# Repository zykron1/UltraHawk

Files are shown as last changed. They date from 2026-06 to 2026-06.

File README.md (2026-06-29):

# UltraHawk
A custom fully autonomous drone designed to run custom firmware on a fully custom flight controller. It is capable of autonomously navigating to waypoints.

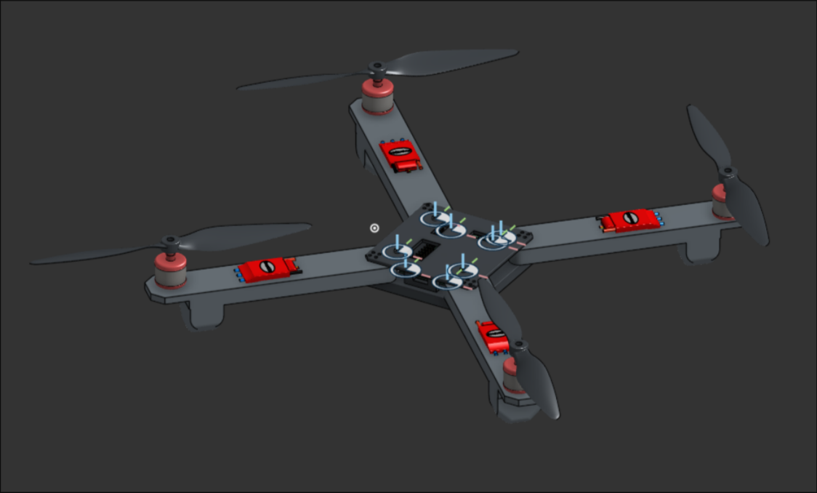
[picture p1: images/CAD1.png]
drone


Ultrahawk utilizes a fully custom PCB made out of SMT components that can be manufactured via a pick-and-place machine, or manually soldered on via hot plate.
You may find KiCAD files in the pcb directory, along with the production folder including a .zip file for easy export to PCB services as JLCPCB and PCBWay.
Components may be found in the `bom.csv` file containing the LCSC part numbers for each part.

UltraHawk also uses a custom frame that is designed to be 3D printed. CAD files for this can be found in the `CAD` folder as `.step` files.

The drone can then be assembled using the rest of the parts such as motors, esc's, and batteries, all of which can be found in the `bom.csv` file.
Perliminary firmware for the project may also be found in the `firmware` directory.

See bom.csv for full price breakdown.
See JOURNAL.md for full work log.

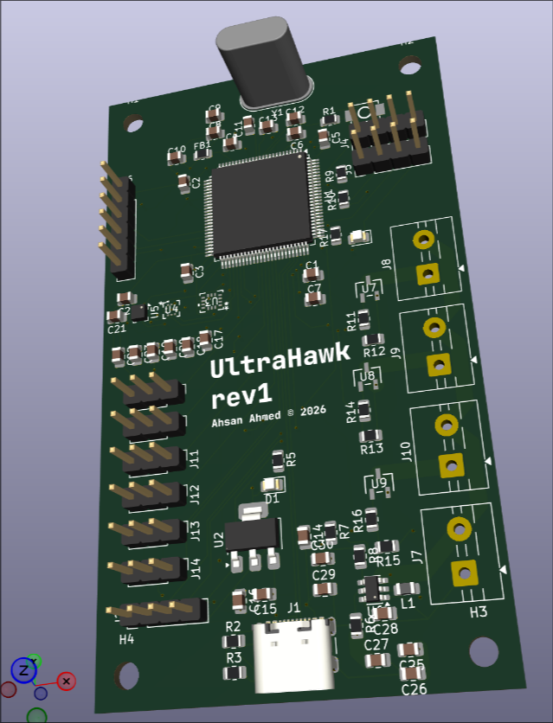
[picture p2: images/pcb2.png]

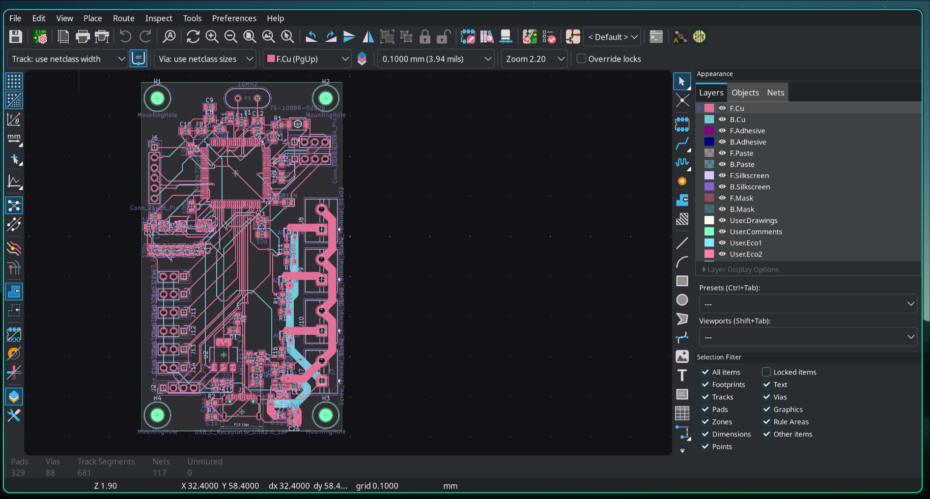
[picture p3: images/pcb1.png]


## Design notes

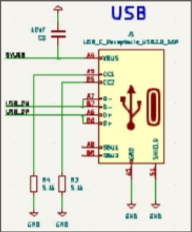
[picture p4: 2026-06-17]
images/usbc.png

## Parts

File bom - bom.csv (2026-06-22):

Designator | Footprint | Quantity | Value | LCSC Part # | Cost Per Unit | Cost | Note
C1, C11, C17, C18, C19, C2, C20, C21_2, C21, C23, C24, C3, C4, C5, C6, C27, C28 | 805 | 17 | 100n | C344180 | $0.02 | $0.35 | Multiples of 10
C10, C14, C9 | 805 | 3 | 1u | C24123 | $0.0195 | $0.39 | moq 20
C12, C13 | 805 | 2 | 34p | C3894194 | $0.0017 | $0.09 | moq 50
C15, C16 | 805 | 2 | 22u | C602037 | $0.1138 | $1.14 | moq 10
C22 | 805 | 1 | 1uf | C28323 | $0.0469 | $0.94 | moq 20
C25, C26 | 805 | 2 | 10µF | C1713 | $0.0491 | $0.98 | moq 20
C29, C30 | 805 | 2 | 22µF | C5674 | $0.07 | $0.70 | moq 10
C7 | 805 | 1 | 10u | C17024 | $0.04 | $0.84 | moq 20
C8 | 805 | 1 | 10n | C1710 | $0.01 | $0.47 | moq 50
D1 | 805 | 1 | RED | C84256 | $0.01 | $0.67 | moq 50
D2 | 805 | 1 | GREEN | C5879267 | $0.42 | $0.42 | no moq
FB1 | 603 | 1 | 120R | C14709 | $0.01 | $0.74 | moq 50
J1 | USB_C_Receptacle_GCT_USB4105-xx-A_16P_TopMnt_Horizontal | 1 | USB_C_Receptacle_USB2.0_16P | C5184243 | $1.17 | $1.17 | no moq
J10, J7, J8, J9 | TerminalBlock_MaiXu_MX126-5.0-02P_1x02_P5.00mm | 4 | Screw_Terminal_01x02 | C5188434 | $0.06 | $0.62 | moq 10
J11, J12, J13, J14, J15, J3 | PinHeader_1x03_P2.54mm_Vertical | 6 | Conn_01x03_Pin | C2337 | $0.16 | $0.78 | moq 5
J2, J4, J5 | PinHeader_1x04_P2.54mm_Vertical | 3 | Conn_01x04_Pin | sharing from above | sharing from above | 0 | sharing from above
J6 | PinHeader_1x06_P2.54mm_Vertical | 1 | Conn_01x06_Pin | sharing from above | sharing from above | 0 | sharing from above
L1 | 805 | 1 | 3.3uh | C18734461 | $0.02 | $0.12 | moq 5
R1, R12, R13, R15, R6, R7 | 805 | 6 | 10k | C84376 | $0.00 | $0.38 | moq 100 | Factory ded
R10, R9 | 805 | 2 | 4.7k | C4176634 | $0.01 | $0.01 | no moq | Factory ded
R11, R14, R16 | 805 | 3 | 100 | C2907218 | $0.00 | $0.32 | moq 100 | Factory ded
R17 | 805 | 1 | 220 | C104105 | $0.00 | $0.26
R2, R3 | 805 | 2 | 5.1k | C2930296 | $0.00 | $0.22 | moq 100
R5 | 805 | 1 | 1k5 | C416128 | $0.00 | $0.26 | moq 100
R8 | 805 | 1 | 54.9k | C137510 | $0.00 | $0.28 | moq 100 | Factory ded
SW1 | SW-SMD_L3.9-W3.0-P4.45 | 1 | TS-1088R-02026 | C455280 | $0.06 | $0.60 | moq 5
U1 | LQFP-100_14x14mm_P0.5mm | 1 | STM32H723VGTx | C730142 | $6.99 | $6.99 | no moq
U2 | SOT-223-3_TabPin2 | 1 | AMS1117-3.3 | C6186 | $0.20 | $0.99 | moq 5
U3 | BMI270_BOS | 1 | BMI270 | C2836813 | $4.15 | $4.15 | no moq
U4 | QFN10_BMP581_BOS | 1 | BMP581 | C5362283 | $4.31 | $4.31 | no moq
U5 | LGA-12_2x2mm_P0.5mm | 1 | LIS3MDL | C478483 | $5.04 | $5.04 | no moq
U6 | SOT-23-6 | 1 | TPS565208 | C2650336 | $0.44 | $0.44 | no moq
U7, U8, U9 | SOT-23-3L_AOS | 3 | AO3400A | C20917 | $0.08 | $0.42 | moq 5
Y1 | Crystal_HC49-U_Vertical | 1 | 16MHZ | C326538 | $0.53 | $0.53 | no moq
 |  |  |  |  |  | $35.63
Name | Cost | Link
JLCPCB Stencil+PCB+Shipping | $18.87 | n/a
BLDC + ESC + Props | $55.99 | https://www.amazon.com/gp/product/B0BW5H7Y8Q/
OVONIC 3S Lipo Battery 50C 5200mAh | $25.54 | https://www.amazon.com/5200mAh-Battery-Connector-Airplane-Helicopter/dp/B07L69B8V6/
LCSC Total(SEE LCSC.CSV!!!) | $35.63 | n/a
LCSC Shipping | $20 | estimate
 | $156.03

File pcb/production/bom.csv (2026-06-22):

Designator | Footprint | Quantity | Value | LCSC Part #
C1, C11, C17, C18, C19, C2, C20, C21_2, C21, C23, C24, C3, C4, C5, C6 | 0805 | 15 | 100n
C10, C14, C9 | 0805 | 3 | 1u
C12, C13 | 0805 | 2 | 34p
C15, C16 | 0805 | 2 | 22u
C22 | 0805 | 1 | 1uf
C25, C26 | 0805 | 2 | 10µF
C27, C28 | 0805 | 2 | 0.1µF
C29, C30 | 0805 | 2 | 22µF
C7 | 0805 | 1 | 10u
C8 | 0805 | 1 | 10n
D1 | 0805 | 1 | RED
D2 | 0805 | 1 | GREEN
FB1 | 0603 | 1 | 120R
J1 | USB_C_Receptacle_GCT_USB4105-xx-A_16P_TopMnt_Horizontal | 1 | USB_C_Receptacle_USB2.0_16P
J10, J7, J8, J9 | TerminalBlock_MaiXu_MX126-5.0-02P_1x02_P5.00mm | 4 | Screw_Terminal_01x02
J11, J12, J13, J14, J15, J3 | PinHeader_1x03_P2.54mm_Vertical | 6 | Conn_01x03_Pin
J2, J4, J5 | PinHeader_1x04_P2.54mm_Vertical | 3 | Conn_01x04_Pin
J6 | PinHeader_1x06_P2.54mm_Vertical | 1 | Conn_01x06_Pin
L1 | IND-SMD_L5.8-W5.2 | 1 | 3.3uh | C2826659
R1, R12, R13, R15, R6, R7 | 0805 | 6 | 10k
R10, R9 | 0805 | 2 | 4.7k
R11, R14, R16 | 0805 | 3 | 100
R17 | 0805 | 1 | 220
R2, R3 | 0805 | 2 | 5.1k
R5 | 0805 | 1 | 1k5
R8 | 0805 | 1 | 54.9k
SW1 | SW-SMD_L3.9-W3.0-P4.45 | 1 | TS-1088R-02026 | C455280
U1 | LQFP-100_14x14mm_P0.5mm | 1 | STM32H723VGTx
U2 | SOT-223-3_TabPin2 | 1 | AMS1117-3.3
U3 | BMI270_BOS | 1 | BMI270
U4 | QFN10_BMP581_BOS | 1 | BMP581
U5 | LGA-12_2x2mm_P0.5mm | 1 | LIS3MDL
U6 | SOT-23-6 | 1 | TPS565208
U7, U8, U9 | SOT-23-3L_AOS | 3 | AO3400A
Y1 | Crystal_HC49-U_Vertical | 1 | 16MHZ

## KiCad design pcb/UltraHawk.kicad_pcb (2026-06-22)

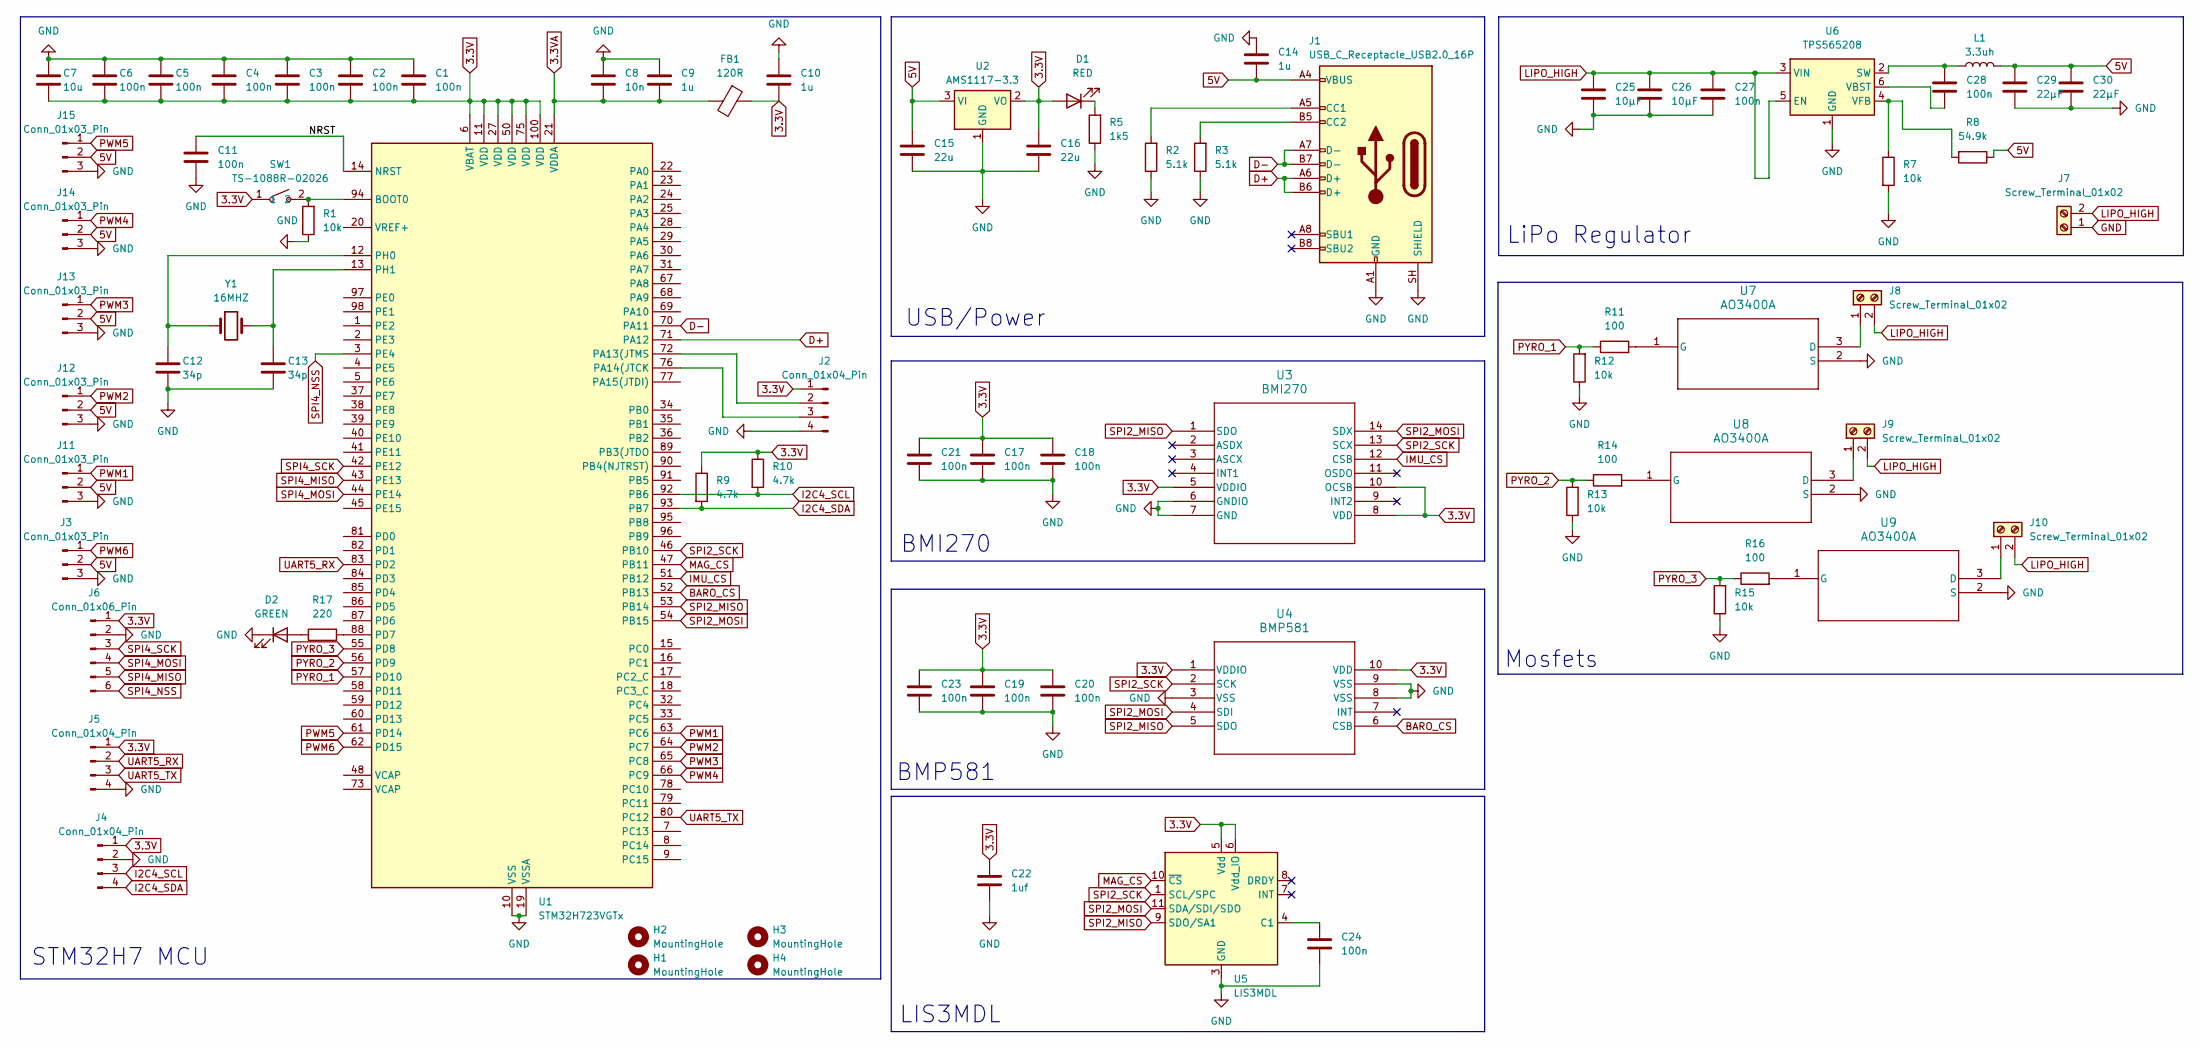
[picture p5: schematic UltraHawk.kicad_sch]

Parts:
C1, C2, C3, C4, C5, C6, C11, C17, C18, C19, C20, C21, C23, C24, C27, C28: 100n; C_0805_2012Metric
C7: 10u; C_0805_2012Metric
C8: 10n; C_0805_2012Metric
C9, C10, C14: 1u; C_0805_2012Metric
C12, C13: 34p; C_0805_2012Metric
C15, C16: 22u; C_0805_2012Metric
C22: 1uf; C_0805_2012Metric
C25, C26: 10µF; C_0805_2012Metric
C29, C30: 22µF; C_0805_2012Metric
D1: RED; LED_0805_2012Metric
D2: GREEN; LED_0805_2012Metric
FB1: 120R; R_0603_1608Metric_Pad0.98x0.95mm_HandSolder
H1, H2, H3, H4: MountingHole; MountingHole_3.2mm_M3
J1: USB_C_Receptacle_USB2.0_16P; USB_C_Receptacle_GCT_USB4105-xx-A_16P_TopMnt_Horizontal
J2, J4, J5: Conn_01x04_Pin; PinHeader_1x04_P2.54mm_Vertical
J3, J11, J12, J13, J14, J15: Conn_01x03_Pin; PinHeader_1x03_P2.54mm_Vertical
J6: Conn_01x06_Pin; PinHeader_1x06_P2.54mm_Vertical
J7, J8, J9, J10: Screw_Terminal_01x02; TerminalBlock_MaiXu_MX126-5.0-02P_1x02_P5.00mm
L1: 3.3uh; IND-SMD_L5.8-W5.2
R1, R7, R12, R13, R15: 10k; R_0805_2012Metric
R2, R3: 5.1k; R_0805_2012Metric
R5: 1k5; R_0805_2012Metric
R8: 54.9k; R_0805_2012Metric
R9, R10: 4.7k; R_0805_2012Metric
R11, R14, R16: 100; R_0805_2012Metric
R17: 220; R_0805_2012Metric
SW1: TS-1088R-02026; SW-SMD_L3.9-W3.0-P4.45; LCSC Part C455280
U1: STM32H723VGTx; LQFP-100_14x14mm_P0.5mm
U2: AMS1117-3.3; SOT-223-3_TabPin2
U3: BMI270; BMI270_BOS
U4: BMP581; QFN10_BMP581_BOS
U5: LIS3MDL; LGA-12_2x2mm_P0.5mm
U6: TPS565208; SOT-23-6
U7, U8, U9: AO3400A; SOT-23-3L_AOS
Y1: 16MHZ; Crystal_HC49-U_Vertical

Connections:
3.3V: C1.2, C2.2, C3.2, C4.2, C5.2, C6.2, C7.2, C10.2, C16.1, C17.1, C18.1, C19.1, C20.1, C21.1, C22.1, C23.1, D1.2 (A), FB1.1, J2.1, J4.1, J5.1, J6.1, R9.1, R10.1, SW1.1, U1.6 (VBAT), U1.11 (VDD), U1.27 (VDD), U1.50 (VDD), U1.75 (VDD), U1.100 (VDD), U2.2 (VO), U3.5 (VDDIO), U3.8 (VDD), U3.10 (OCSB), U4.1 (VDDIO), U4.10 (VDD), U5.5 (Vdd), U5.6 (Vdd_IO); also elsewhere on the board
3.3VA: C8.2, C9.2, FB1.2, U1.21 (VDDA)
5V: C14.2, C15.1, C29.1, C30.1, J1.A4 (VBUS), J1.A9 (VBUS), J1.B4 (VBUS), J1.B9 (VBUS), J3.2, J11.2, J12.2, J13.2, J14.2, J15.2, L1.1, R8.1, U2.3 (VI)
/NRST: C11.1, U1.14 (NRST)
BARO_CS: U1.52 (PB13), U4.6 (CSB)
D+: J1.A6 (D+), J1.B6 (D+), U1.71 (PA12)
D-: J1.A7 (D-), J1.B7 (D-), U1.70 (PA11)
GND: C1.1, C2.1, C3.1, C4.1, C5.1, C6.1, C7.1, C8.1, C9.1, C10.1, C11.2, C12.2, C13.2, C14.1, C15.2, C16.2, C17.2, C18.2, C19.2, C20.2, C21.2, C22.2, C23.2, C24.2, C25.2, C26.2, C27.2, C29.2, C30.2, D2.1 (K), J1.A1 (GND), J1.A12 (GND), J1.B1 (GND), J1.B12 (GND), J1.SH (SHIELD), J2.4, J3.3, J4.2, J5.4, J6.2, J7.1, J11.3, J12.3, J13.3, J14.3, J15.3, R1.1, R2.1, R3.1, R5.1, R7.2, R12.1, R13.1, R15.1, U1.10 (VSS), U1.19 (VSSA), U1.26 (VSS), U1.49 (VSS), U1.74 (VSS), U1.99 (VSS), U2.1 (GND), U3.6 (GNDIO), U3.7 (GND), U4.3 (VSS), U4.8 (VSS), U4.9 (VSS), U5.2 (GND), U5.3 (GND), U5.12 (GND), U6.1 (GND), U7.2 (S), U8.2 (S), U9.2 (S); also elsewhere on the board
I2C4_SCL: J4.3, R10.2, U1.92 (PB6)
I2C4_SDA: J4.4, R9.2, U1.93 (PB7)
IMU_CS: U1.51 (PB12), U3.12 (CSB)
LIPO_HIGH: C25.1, C26.1, C27.1, J7.2, J8.2, J9.2, J10.2, U6.3 (VIN), U6.5 (EN); also elsewhere on the board
MAG_CS: U1.47 (PB11), U5.10 (~CS)
unnamed: D1.1 (K), R5.2
unnamed: D2.2 (A), R17.1
unnamed: J1.A5 (CC1), R2.2
unnamed: J1.B5 (CC2), R3.2
unnamed: J2.2, U1.72 (PA13(JTMS)
unnamed: J2.3, U1.76 (PA14(JTCK)
unnamed: J8.1, U7.3 (D)
unnamed: J9.1, U8.3 (D)
unnamed: J10.1, U9.3 (D)
unnamed: R1.2, SW1.2, U1.94 (BOOT0)
unnamed: R17.2, U1.88 (PD7)
unnamed: C12.1, U1.12 (PH0), Y1.1
unnamed: C13.1, U1.13 (PH1), Y1.2
unnamed: C24.1, U5.4 (C1)
unnamed: C28.1, L1.2, U6.2 (SW)
unnamed: C28.2, U6.6 (VBST)
unnamed: R7.1, R8.2, U6.4 (VFB)
unnamed: R11.2, U7.1 (G)
unnamed: R14.2, U8.1 (G)
unnamed: R16.2, U9.1 (G)
PWM1: J11.1, U1.63 (PC6)
PWM2: J12.1, U1.64 (PC7)
PWM3: J13.1, U1.65 (PC8)
PWM4: J14.1, U1.66 (PC9)
PWM5: J15.1, U1.61 (PD14)
PWM6: J3.1, U1.62 (PD15)
PYRO_1: R11.1, R12.2, U1.57 (PD10)
PYRO_2: R13.2, R14.1, U1.56 (PD9)
PYRO_3: R15.2, R16.1, U1.55 (PD8)
SPI2_MISO: U1.53 (PB14), U3.1 (SDO), U4.5 (SDO), U5.9 (SDO/SA1)
SPI2_MOSI: U1.54 (PB15), U3.14 (SDX), U4.4 (SDI), U5.11 (SDA/SDI/SDO)
SPI2_SCK: U1.46 (PB10), U3.13 (SCX), U4.2 (SCK), U5.1 (SCL/SPC)
SPI4_MISO: J6.5, U1.43 (PE13)
SPI4_MOSI: J6.4, U1.44 (PE14)
SPI4_NSS: J6.6, U1.3 (PE4)
SPI4_SCK: J6.3, U1.42 (PE12)
UART5_RX: J5.2, U1.83 (PD2)
UART5_TX: J5.3, U1.80 (PC12)

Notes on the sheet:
USB/Power
BMI270
LiPo Regulator
BMP581
Mosfets
STM32H7 MCU
LIS3MDL

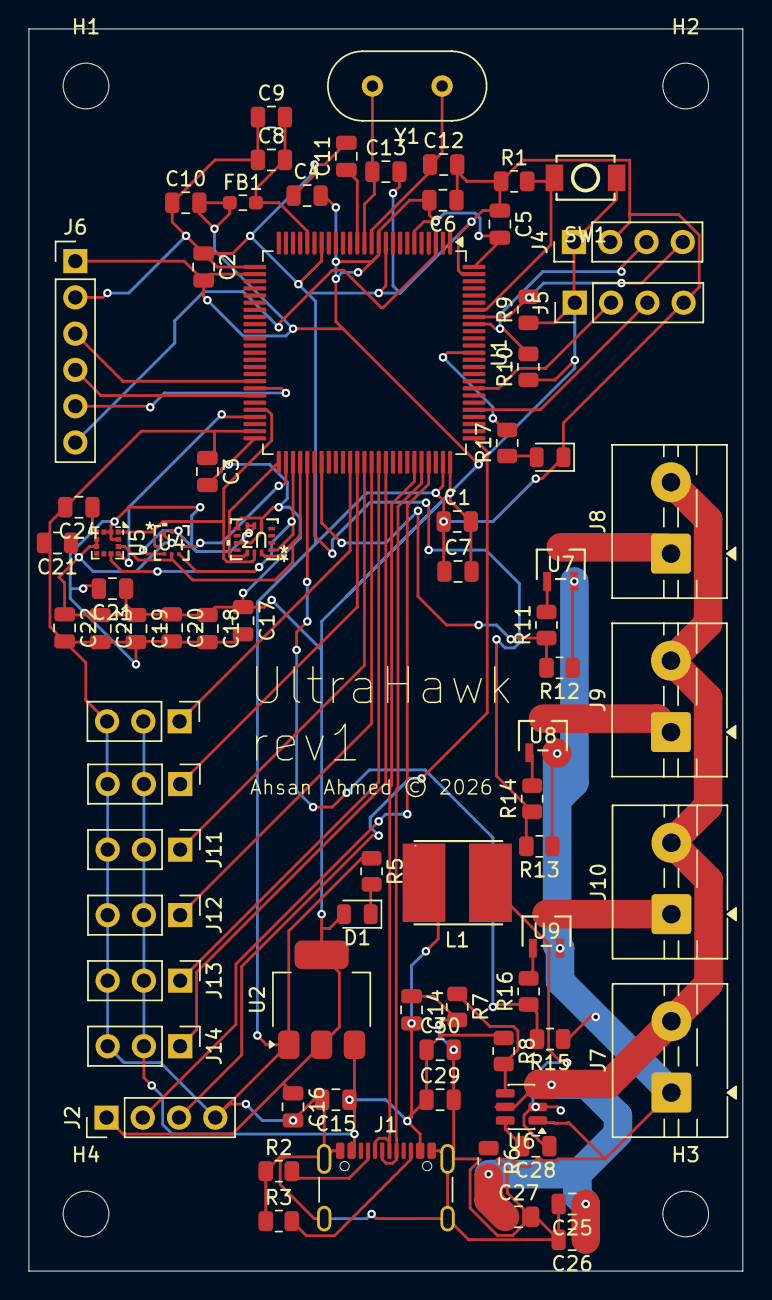
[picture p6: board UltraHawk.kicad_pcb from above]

Board: 2 copper layers, 50.0 x 87.0 mm, 81 parts (0 on the bottom side), 51 nets.

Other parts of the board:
C21#2: 100n; C_0805_2012Metric
R6: 10k; R_0805_2012Metric

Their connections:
3.3V: C21#2.1; also elsewhere on the board
GND: C21#2.2; also elsewhere on the board
LIPO_HIGH: R6.2; also elsewhere on the board

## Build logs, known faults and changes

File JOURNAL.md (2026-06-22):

# Journal

## 21 June 2026 - 1 hour
I wrote some basic arduino c++ style code that simply implements a PID loop which maintains orientation and attitude using the barometer and IMU.
Realistitcally, for performance reasons I would have to rewrite this using the STM32 HAL and FreeRTOS or Zephyr. For now however, this should be enough to hover.

# 21 June 2026 - 2 hours

## Wrapping up loose ends.
I began by first finalizing my pin choices, ensuring the pcb meets DRC rules, before then going to JLCPCB to get a quote, and building a final BOM.csv.
I realized how sketchy the pricing model is, as changing my stencil size by a few milimeters resulted in far cheaper or expensive build costs and shipping fees.
Once I got that done, the estimated quote was roughly $18.87. Let me do some budget math. Assuming the LCSC grand total is 50 dollars, that leaves $111.13 left.
From that, I found a motor + prop + ESC kit on amazon for about $56 with free shipping. That leaves $55.13 left for purchasing batteries, chargers, and GPS.
For optimal use, I decided to go with a 5200mAh battery which price about $35 dollars. That $20 dollars ish left, which I'd rather all invest into GPS than radio.

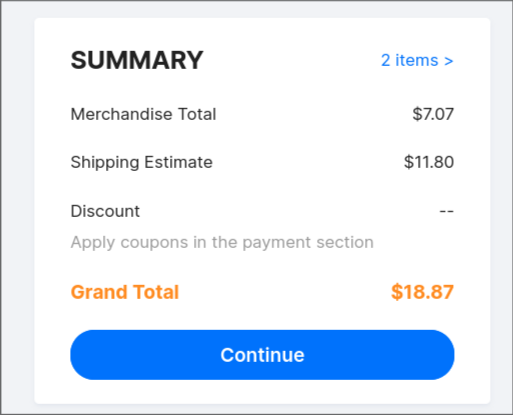
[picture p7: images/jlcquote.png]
JLC pcb order

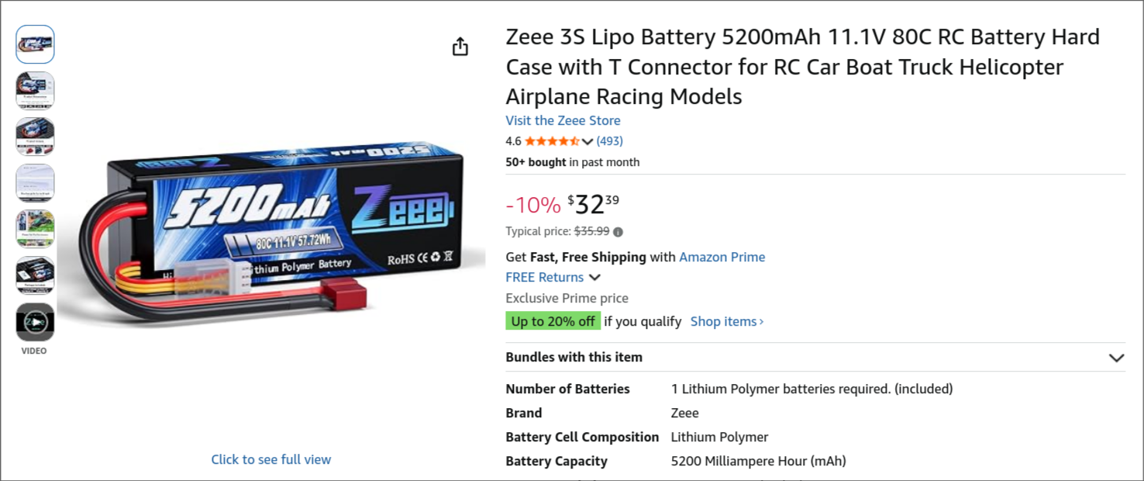
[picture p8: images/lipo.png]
3S Lipo Candidate

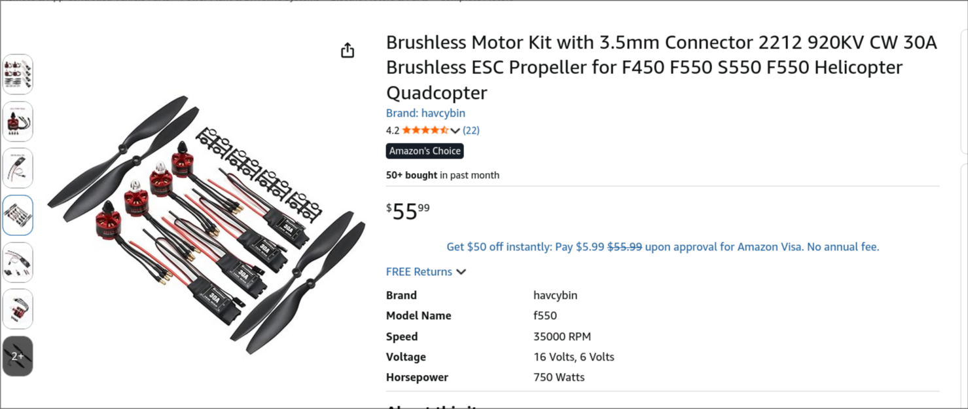
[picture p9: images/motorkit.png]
Motor kit


# 21 June 2026 - 4 hours
I completed perliminary CAD of my drone. I began by making a PCB tombstone mount, before then designing a top plate, and arms.
CAD Model of the Drone

Here are some more detailed images.

Here is the PCB mount:
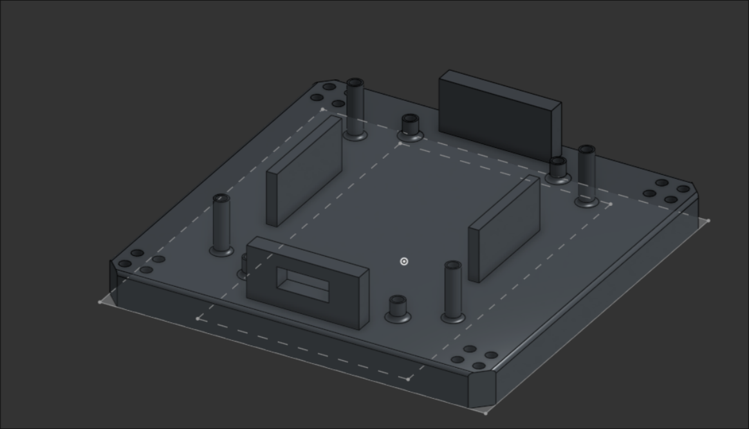
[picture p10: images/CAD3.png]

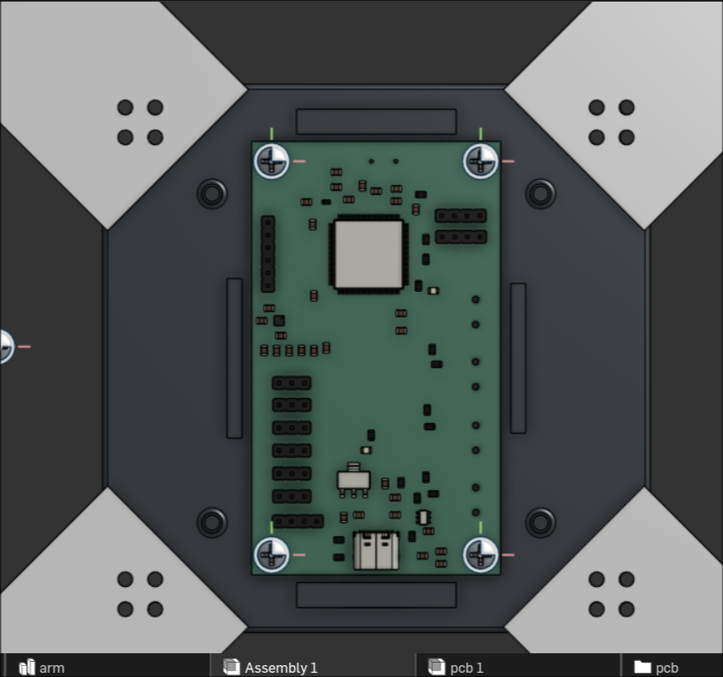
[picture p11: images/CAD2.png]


I decided to use a tombstone style mounting system rather than fully encasing the pcb properly. Here's a top view of the entire craft:

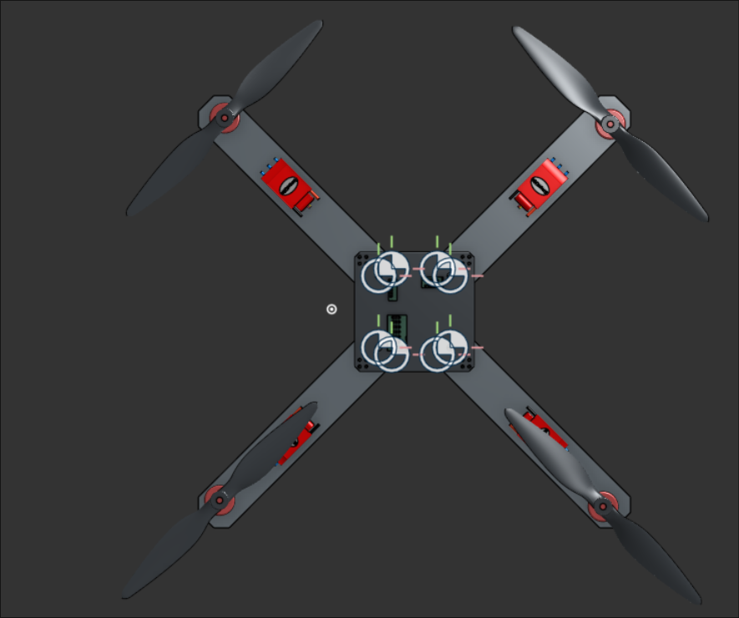
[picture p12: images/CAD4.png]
CAD model of the top view of the drone


I'll work on the battery mount and software next, once I can get confirmation from LCSC that all my parts can be ordered.

## 20 June 2026 - 3 hours
After exporting my design into JLCPCB, I only have bad news. Firstly, all the sensors that I chose require me to upgrade to standard PCBA, and not economic.
Secondly, the prices are already insane, pushing 200 dollars, and with the cheapest possible shipping + tarrifs, I end up with a grand total of about $300.
Lucky for me, I know someone who owns a SMD hot plate, so if I can just use the hack club funding to aquire myself the SMD components and the PCB I'm fine.

I also received some advice on reddit about my design that I implemented. After that, I set out to find a LCSC part number for EVERY SINGLE PART on my board.
This took about 1.5 hours, and then I had to verify that I hadn't made any mistakes. Once that was done, I had a rough estimate of about $40 of just parts.
I'm hoping to get S tier for this project as its going to serve as a platform for building a fully custom autonomous drone platform with:

 - custom firmware
 - custom flight computer
 - custom overall chasis/drone
 - expandibility and usefulness for other makers

This project will for now remain for autonomous drones, but with the large amount of added IO (SPI, UART, I2C), it should be possible to connect a radio and GPS.

Once I made my finalizing edits I went to JLCPCB to calculate the total cost of getting a stencil and pcb.

## 17 June 2026 - 7 hours
After about 7 hours of work, I finally managed to route the entire board. I had to learn a lot. I first began by realizing how bad my current pin choices were.
Often, SPI pins were too far apart, or just on the wrong side of the entire MCU. Once I got that down, I had to go through the pain of placement.
Originally, I began by placing everything and then trying to route, but that quickly led to issues and wasted a couple of hours. I then pivoted to a mix.

I placed down all large components first, before then adding sensors one by one, along with their decoupling capacitors. Then I set up power.
I had to create large 5V, 3.3V, and GND rails that allowed power to reach all important areas of the entire board, while ensuring to avoid many vias.
After all of this, I ended up with a fairly good board, but had to deal with DRC errors relating to the fact that the footprints of certain Bosch chips are tight.

Result:

PCB fully routed
PCB 3D render

I'm really proud of the result. I also asked on Reddit for help on analyzing my work and found no really large issues with the schematic.

## 17 June 2026 - 1 hour
I went through the entire schematic and found footprints for each element. I had to go to LCSC and use a special tool to turn EasyEDA footprints into KiCad.
Once I was done, I decided to check every footprint visually and then imported it all into a PCB.

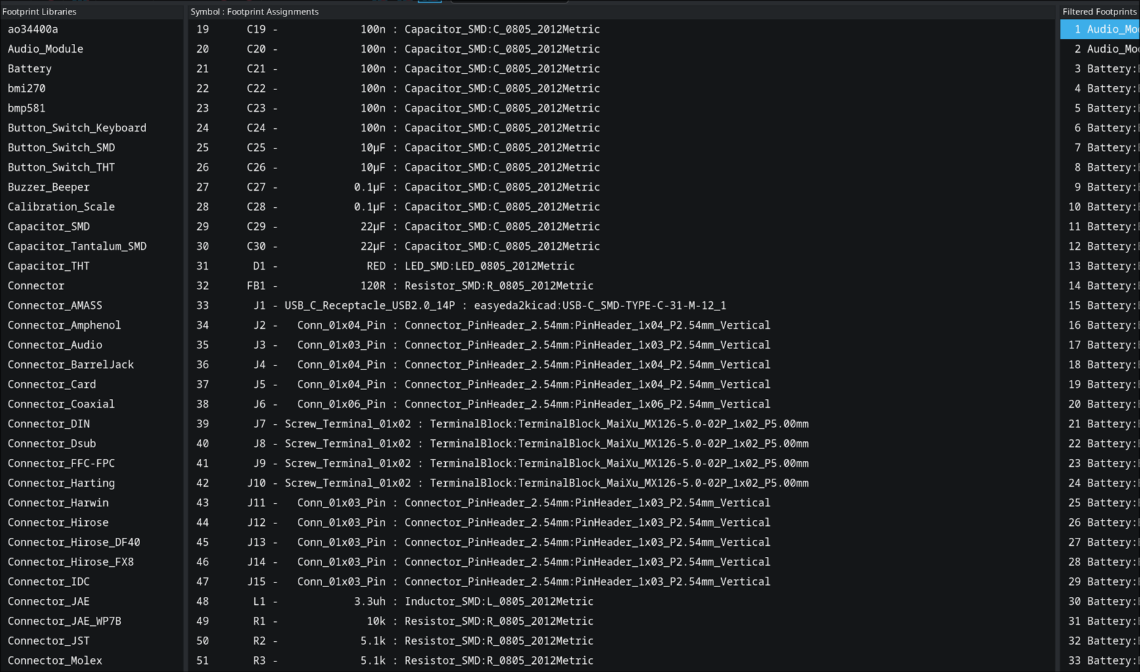
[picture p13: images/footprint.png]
Footprints


Imported into a pcb:

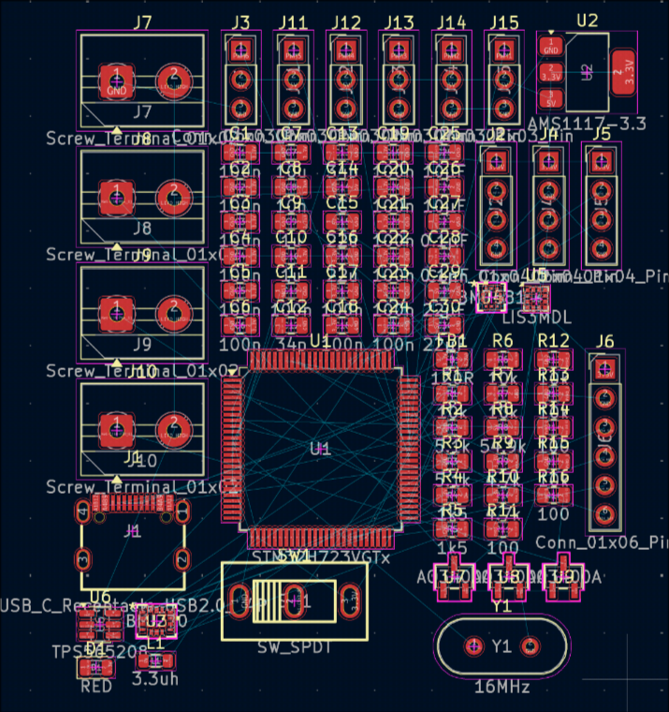
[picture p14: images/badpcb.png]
PCB with no placement or routing

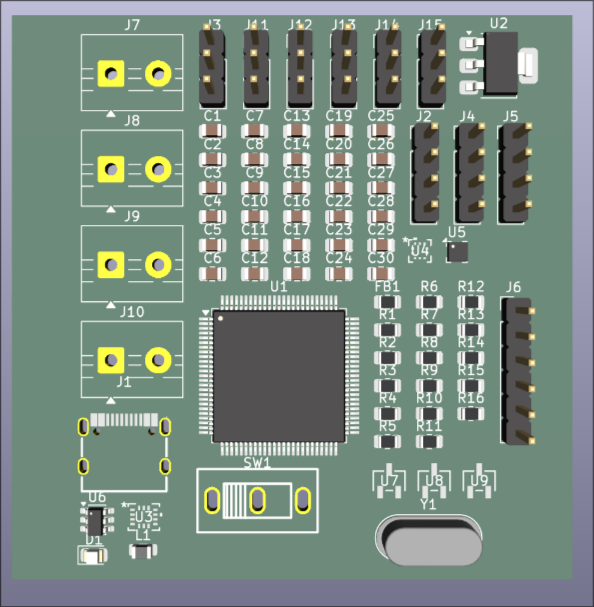
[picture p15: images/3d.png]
PCB with no placement or routing 3D model


## 17 June 2026 - 2 hours
I decided to add a ton of GPIO just in case stuff is broken. I added an external SPI bus, an external UART, and an I2C bus.
This should allow for expansion when I acquire a radio and/or a GPS module. I also needed to find a proper N-type MOSFET and wire it correctly.
This is because most rockets need to fire parachute ejection or motor re-light charges mid-flight, which can't be done through GPIO for obvious reasons.
I chose the AOS AO3400A since it had **TONS** of stock.

1.1 million of stock

I then added 6 PWM ports for support for hexacopters, and began analyzing my design to find any obvious faults 

## 17 June 2026 - 3 hours
Other than the Flight Computer, the entire project is, in fact, an autonomous drone.
The goal of the drone is to be able to autonomously travel to GPS coordinates, as well as perform automatic landings using April Tag detection.
This means I have to make a custom flight computer, frame, and fully custom firmware. I hope this project helps me break into the embedded space.

To do this, I need to figure out how drones work specifically. Most drones use BLDC motors, which require specialized controllers (ESCs) to operate.
ESC's are rated by amps, while most drone BLDC motors are rated by KV(RPM / Voltage). I need to find a capable yet affordable pair of these.
Also, Lithium Polymer(LiPo) batteries are typically used to power these setups. They are typically measured in the amount of 3.3V cells (s) and a C rating.
C ratings, when multiplied by the amount of Amp-Hours(Ah) a battery has, yield the maximum safe amount of current they can discharge.

I don't need much power, so a 3S (11.1V nominal) architecture will work fine for now.
I often find people using 1000 kV motors for drones at this scale, so I did the math:

1000 KV * 11.1 V = 11,100 RPM

This sounds pretty promising, but what about the current it draws? Although this is dependent on the load that is driving, typically, people report 15 to 20 amps.
If I purchase 4x 20A ESCs, I'd be drawing about 100 amps, which is a ridiculous number to think about. Assuming a common 3s 120c 2200 mAh battery:

2200 mAh / 1000 = 2.2 Ah
2.2 Ah * 120 C = 264 Amps

264 Amps continuous is more than enough for something like this. It also allows room for upgradability in the future with more power-hungry ESCs and motors.

All this research leads to this current setup:
 - 4x 20A ESC's
 - 1x 3S 2200mAh 120C LiPo battery
 - 4x 1000 KV drone motors
 - 4x Compatible props

Now, I went to try to come up with a cost estimate for such a setup. I started by looking for a LiPo battery.
The best rate I could find that wasn't extremely sketchy was about $28 USD for a kit of two batteries.
Then, for motors, it was really hard to find a **real** rate on Aliexpress. Tons of welcome deals and buy-one-only scams.
The issue is, I can't find anything that isn't a welcome deal. And on top of that, most of those are buy-one-only.
With that being said, at a rate of roughly 20 dollars for a motor+esc kit, that brings the total cost to about $80 USD.
I realize, though, that I can just buy multiple welcome deals to get an extremely cheap setup.

Finally, I looked into Amazon pricing. And to my luck, I found a $32 kit with free shipping that had four motors.

Overall, I'd say the time was well spent doing the research I needed. I plan on 3D printing myself a custom frame using my 3D printer, so that won't be an issue.

## 16 June 2026 - 6 hours
The goal today is to fully complete a schematic of the entire board. I began by updating KiCAD and setting up the MCU.
Importing the STM32H723VGT6 made me realize how large the chip was, as well as the insane amount of pins available.
I've done MCU schematics before, but STM32 is a new world for me, so I began looking for tutorials for STM32 devboards.

In about an hour or so, I got to the point that I had the MCU wired up to the USB-C connector with an external crystal.
I then got a random 5V to 3.3V step-down linear regulator to power the STM32 due to its high supply on LCSC.

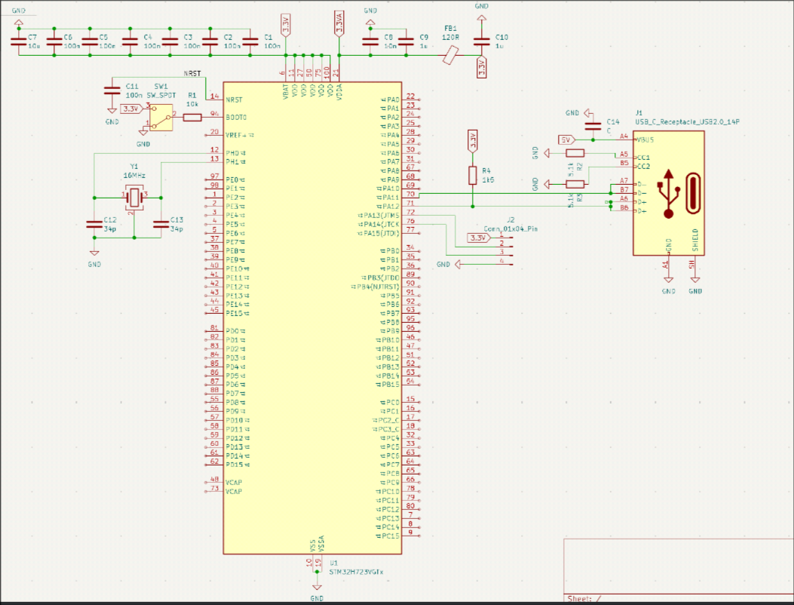
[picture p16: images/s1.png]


I then imported the BMI270 IMU and set up decoupling caps and data signal lines. I had some trouble understanding, as the chip is designed for both I2C and SPI.
I then spent about 20 minutes tidying my design and organizing everything into boxes for more clarity, as well as simplifying unusual wiring.

Then I realized, LCSC doesn't have any stock for the BMP390. Turns out, like always, I ended up with another supply chain issue.
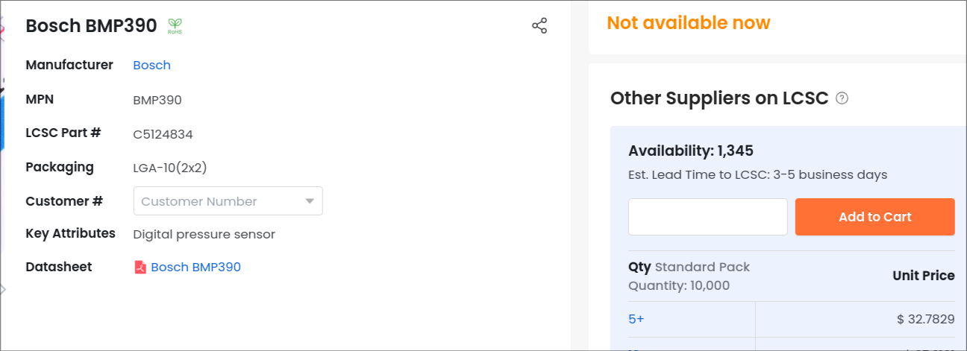
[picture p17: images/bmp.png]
LCSC out of stock

Luckily for me, Bosch has developed a better barometer than the BMP390, the BMP581, which had adequate stock on LCSC.

Finally, for the magnetometer, I decided to switch to the BMM150 thanks to its lower price, and at this rate, all my sensors are made by Bosch.
It should be noted, however, that the BMM150 is discontinued and will never be restocked again. I'm sure this will never become an issue in the future!

Actually, screw that, I'm sticking with the LIS3MDL magnetometer as it's a pretty safe bet. It's also made by ST, so drivers should be easy.

Finally, for the part I'm dreading the most, the TPS56208. It's needed because its job is to allow the flight computer to power on through just LiPo power.
After tons of reading datasheets and careful wiring, I finally finished it. I'm still a bit unsure about it, but I did email TI, and they were helpful last time.
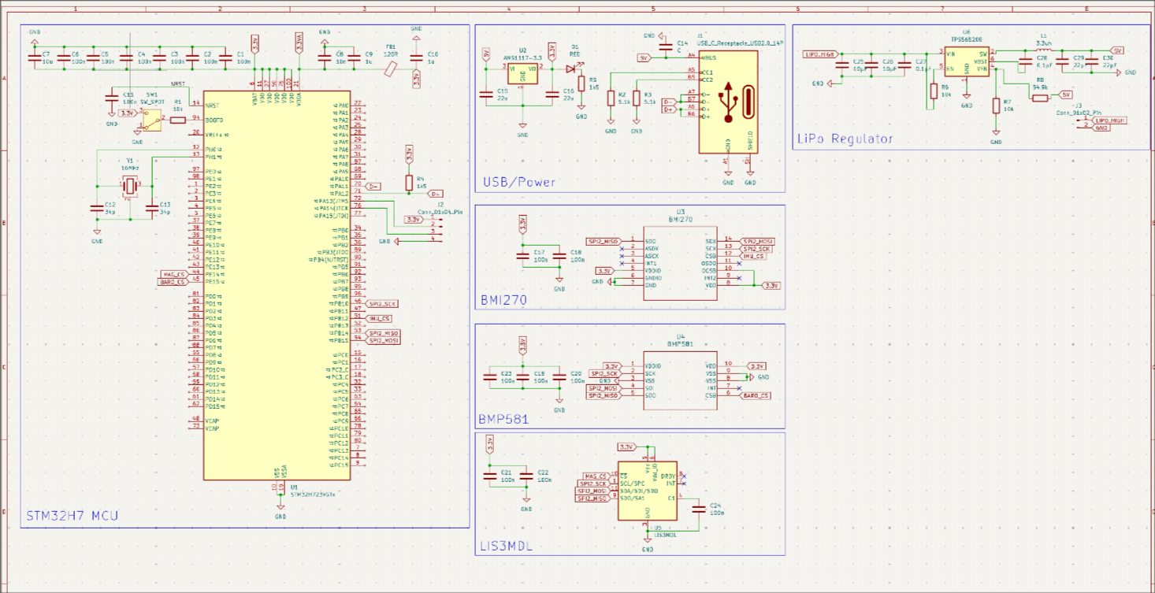
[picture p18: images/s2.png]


## 15 June 2026 - 4 Hours
The goal of this project is to develop a custom flight computer that can be used for custom autonomous drone and rocket operations.

The first part that I went into was part selection. I need to find a capable MCU, a good Inertial Measurement Unit, and a good barometer.
Another goal of this board is to use parts that are well in stock on both JLC's LCSC, as well as DigiKey's store.
I have had extremely negative situations with IMU and Barometer supply chain issues in the past, and do not wish to repeat these.

MCU selection:
Although in my opinion the best MCUs for performance to dollar are Espressif Systems' ESP32 series, often, due to their large nature, they require expensive PCBA.
When researching solutions from other people around the world, the STM32 series from STMicroelectronics always comes up, so I decided to do some research

---

| Family  | Part | Core | Max Clock | Flash  | RAM |
| --- | --- | --- | --- | --- | --- |
| STM32F0 | STM32F072C8  | Cortex-M0  | 48 MHz | 64 KB  | 16 KB  |
| STM32F1 | STM32F103C8  | Cortex-M3  | 72 MHz | 64 KB  | 20 KB  |
| STM32F3 | STM32F303K8  | Cortex-M4F | 72 MHz | 64 KB  | 16 KB  |
| STM32F4 | STM32F407VG  | Cortex-M4F | 168 MHz | 1 MB | 192 KB |
| STM32F7 | STM32F767ZI  | Cortex-M7  | 216 MHz | 2 MB | 512 KB |
| STM32G0 | STM32G071RB  | Cortex-M0+ | 64 MHz | 128 KB | 36 KB  |
| STM32G4 | STM32G474RE  | Cortex-M4F | 170 MHz | 512 KB | 128 KB |
| STM32H7 | STM32H743ZI  | Cortex-M7  | 400 MHz | 2 MB | 1 MB |
| STM32L4 | STM32L476RG  | Cortex-M4F | 80 MHz | 1 MB | 128 KB |

---

Going through the list, the only two that interest me F7 series and the H7 series for their high performance. 
I decided to go with the STM32H7, but I now needed to select which one based on price, flash size, and clock speed.
After some searching, I found this listing on LCSC:

---
| Series | Core(s) | Max Clock | Flash (max) | RAM | LCSC Price (from) | Representative Part |
|---|---|---|---|---|---|---|
| **STM32H723/733** | M7 | 550 MHz | 1 MB | 564 KB | $6.99 | STM32H723VGT6 |
---

Thanks to the insane clock speed and good pricing, I decided to choose this as my MCU.

IMU selection:
I have used multiple IMU's before, and I have had great issues with finding those that remain stable through multiple vendors.
I've previously used the TDK ICM-42688-P, but due to supply chain issues, I ended up with a useless board with no IMU available. 
Avoiding previous mistakes, I settled on the Bosch BMI270 thanks to its well-documented nature in the world of drones, leading to a steady supply.

Barometer selection:
Barometers are extremely important, and I end up neglecting their selection and using out-of-stock or discontinued sensors, so I decided to be careful.
I decided to go with the Bosch BMP390 this time, thanks to its low noise, good supply chain consistency, and existing drivers for the STM environment

Magnetometer selection:
Although not that important for rocketry, magnetometers are extremely important when performing autonomous navigation in drones.
Following a similar philosophy to the IMU and Barometer solution, I ended up on the LIS3MDL.

Power system:
The STM32H7 chip, as well as most sensors, all run on 3.3V logic, while ESCs and USB typically provide 5V.
I decided to go with the AMS117-3.3 following previous projects, and its well-documented nature.

However, for rockets, I need a proper voltage regulator that can take LiPo input voltage and bring it down to 5 volts.
Following suit with previous designs, I decided to choose the TPS56208 from Texas Instruments.

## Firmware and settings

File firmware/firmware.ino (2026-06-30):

#include <Arduino.h>
#include <Wire.h>
#include <WiFi.h>
#include <esp_now.h>
#include "Drone.h"
#include "MPU6050.h"
#include "StateEstimator.h"
#include "PID.h"

// Must be the same on GCS
enum States {
	IDLE,
	TELEOP,
	AUTON,
};

typedef struct __attribute__((packed)) {
	size_t packet_number;
	float missionTime;
	States state;
	float gx, gy, gz, ax, ay, az; // imu data
	float roll, pitch, yaw; // orientation
	float x, y, z; // location
	float m1, m2, m3, m4;
} TelemetryPacket;

typedef struct __attribute__((packed)) {
	States state;
	float thrust, roll, pitch, yaw; // if teleop
	float xpos, ypos, zpos; // if auton
} Command;

uint8_t broadcastAddress[] = {0xFC, 0x01, 0x2C, 0xD0, 0x77, 0x5C};

MPU6050 imu;
StateEstimator estimate;
MPU6050Data i;

uint32_t startTime = 0;
uint32_t lastTime = 0;

Command currentCommand = {IDLE, 0,0,0,0,0,0,0};

void OnDataRecv(const uint8_t * mac, const uint8_t *incomingData, int len) {
	memcpy(&currentCommand, incomingData, sizeof(currentCommand));
}

Drone drone(2, 3, 10, 9);
PID rollController(5, 1, 2);
PID pitchController(5, 1, 2);
PID yawController(5, 1, 2);

void setup () {
	Wire.begin(6, 7);

	imu.init(0x68);
	Serial.begin(9600);

	delay(1000);
	imu.calibrate(500, 10);
	Serial.printf("{%f, %f, %f} \n", imu.drift.gx, imu.drift.gy, imu.drift.gz);

	drone.initMotors();

	WiFi.mode(WIFI_STA);
	esp_now_init();
	esp_now_register_recv_cb(esp_now_recv_cb_t(OnDataRecv));

	esp_now_peer_info_t peerInfo = {};
	memcpy(peerInfo.peer_addr, broadcastAddress, 6);
	peerInfo.channel = 0;  
	peerInfo.encrypt = false;
	esp_now_add_peer(&peerInfo);

	startTime = micros();
	lastTime = startTime;
}

const uint32_t PERIOD_US = 10000; 
size_t packet_number = 0;
void loop () {
	uint32_t now = micros();
	float t = (now - startTime) / 1000000.0f;
	if (now - lastTime >= PERIOD_US) {
		float actual_ms = (now - lastTime) / 1000.0f;
		lastTime += PERIOD_US;

		// State management
		i = imu.getData();

		estimate.updateState({i.gx, i.gy, i.gz}, {i.ax, i.ay, i.az}, 0.0f, actual_ms); 
		Vector3 o = estimate.getOrientation() * RAD_TO_DEG;
		Vector3 p = estimate.getPosition();
		
		float rollCmd, pitchCmd, yawCmd;
		// Handle drone states
		switch (currentCommand.state) {
			case IDLE: {
				break;
			}
			case TELEOP: {
				float rollSetPoint = currentCommand.roll;
				float pitchSetPoint = currentCommand.pitch;
				float yawSetPoint = currentCommand.yaw;
				float thrust = currentCommand.thrust;

				rollCmd = rollController.updateLoop(o.x, rollSetPoint, 0.01);
				pitchCmd = pitchController.updateLoop(o.y, pitchSetPoint, 0.01);
				yawCmd = yawController.updateLoop(o.z, yawSetPoint, 0.01);

				drone.writeMotors(thrust, rollCmd, pitchCmd, yawCmd);
				break;
			}
			case AUTON: {
				break;
			}
		}

		// Telemetry
		TelemetryPacket telem = {
			packet_number,
			t,
			currentCommand.state,
			i.gx, i.gy, i.gz,
			i.ax, i.ay, i.az,
			o.x, o.y, o.z,
			p.x, p.y, p.z,
			drone.t1, drone.t2, drone.t3, drone.t4
		};

		esp_now_send(broadcastAddress, (uint8_t*)&telem, sizeof(telem));
		packet_number++;
	}
}

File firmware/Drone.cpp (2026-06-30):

#include <esp32-hal-ledc.h>
#include "Drone.h"

void Drone::initMotors() {
	ledcAttach(this->m1, 50, 16);
	ledcAttach(this->m2, 50, 16);
	ledcAttach(this->m3, 50, 16);
	ledcAttach(this->m4, 50, 16);
}

uint16_t Drone::pulseToDuty(uint16_t pulse_us) {
    constexpr uint32_t MAX_DUTY = (1 << 16) - 1;
    constexpr uint32_t PERIOD_US = 20000; // 50 Hz
    return (pulse_us * MAX_DUTY) / PERIOD_US;
}

void Drone::writeESC(int pin, uint16_t pulse_us) {
    ledcWrite(pin, pulseToDuty(pulse_us));
}

void Drone::writeMotors(int thrust, int roll, int pitch, int yaw) {
	t1 = thrust + pitch + roll - yaw;
	t2 = thrust + pitch - roll + yaw;
	t3 = thrust - pitch - roll - yaw;
	t4 = thrust - pitch + roll + yaw;

	t1 = constrain(1000 + t1 * 10, 1000, 2000);
	t2 = constrain(1000 + t2 * 10, 1000, 2000);
	t3 = constrain(1000 + t3 * 10, 1000, 2000);
	t4 = constrain(1000 + t4 * 10, 1000, 2000);

	writeESC(m1, t1);
	writeESC(m2, t2);
	writeESC(m3, t3);
	writeESC(m4, t4);
}

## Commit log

2026-06-17 Journal Update #2
    [UltraHawk.kicad_pcb, UltraHawk.kicad_sch]
2026-06-17 Journal Update #3
    [UltraHawk.kicad_sch]
2026-06-17 Journal Update #4
    [UltraHawk.kicad_pcb, UltraHawk.kicad_sch]
2026-06-18 Pcb layout
    [UltraHawk.kicad_pcb, UltraHawk.kicad_sch]
2026-06-18 Journal Update #5
    [UltraHawk.kicad_pcb, UltraHawk.kicad_sch]
2026-06-18 Include PCB images in README
    Add images of the PCB to the README.
2026-06-18 DRC fixes
    [UltraHawk.kicad_pcb]
2026-06-20 Journal Update
    [UltraHawk.kicad_pcb, UltraHawk.kicad_sch, bom.csv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]
2026-06-21 CAD Writeup
2026-06-21 CAD sync'
2026-06-30 PID Hover

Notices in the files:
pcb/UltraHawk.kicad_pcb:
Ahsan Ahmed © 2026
